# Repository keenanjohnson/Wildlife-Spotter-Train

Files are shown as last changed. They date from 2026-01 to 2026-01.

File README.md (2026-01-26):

# Wildlife Spotter Train



Explore the wilderness via Train! BLE-controlled LEGO City train using an ESP32-S3 microcontroller. Features real-time video streaming and playful interaction design. Currently in active development.

https://github.com/user-attachments/assets/2e25facd-4201-4223-821a-3176ae2201d8

This project is a Work in Progress but features:

- A small camera module attached to an ESP32-S3 microcontroller
- A 3D printed enclosure with integrated stand and antenna placement as well as LEGO compatible mounts
- Pybricks firmware running on the train to receive drive commands via Bluetooth
- ESP-IDF firmware on the camera module to stream video over UDP and send commands to the train via Bluetooth
- Fun

<p float="left">
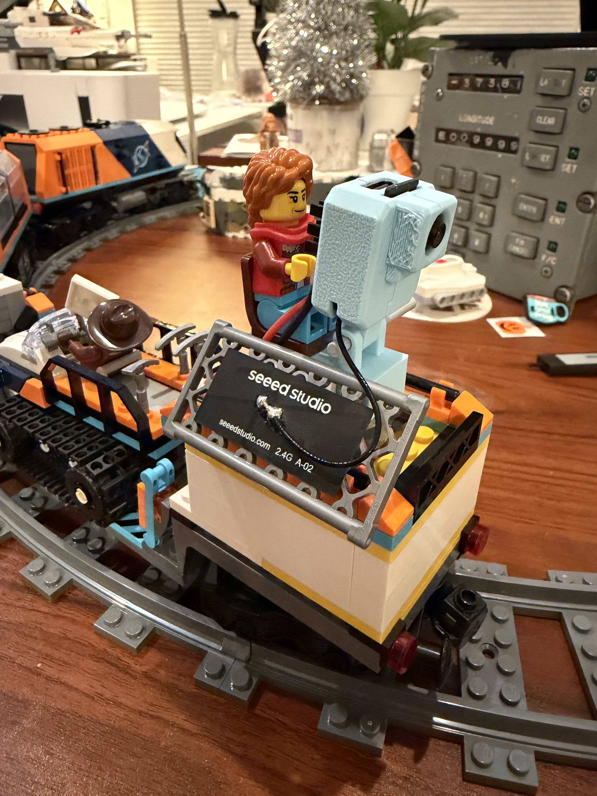
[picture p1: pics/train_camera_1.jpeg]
  
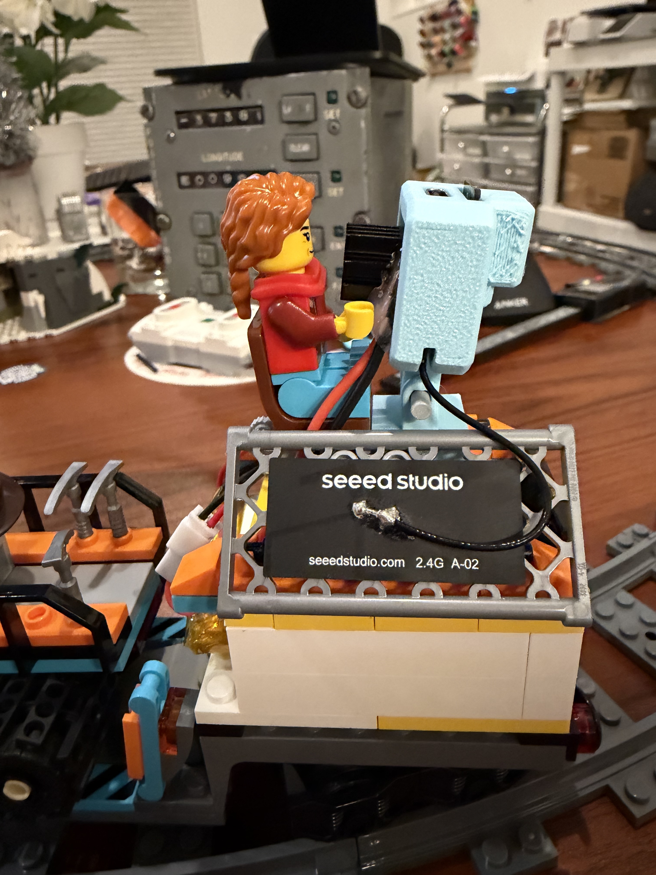
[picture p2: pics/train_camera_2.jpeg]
  
</p>

https://github.com/user-attachments/assets/5a5532dc-e645-4069-b709-44a688e2fda8

## The story

I recently found myself in possesion of one of the Lego artic train sets, which is among one of the most fun recent kits. [kit link #60470](https://www.lego.com/en-us/product/explorers-arctic-polar-express-train-60470). On the back of the artic train is a camera tripod for spotting wildlife, specifically the artic foxes that are included in the kit.



I have recently been doing much ecology and as an embedded systems engineer, I thought it would be fun to improve the set by adding a real camera to the kit.

Additionally, I had seen the excellent [Pybricks](https://pybricks.com/) project and realized that I could also make a device via Bluetooth control and software GUI that would not only stream video but also control the driving of the train.

## System Architecture

```
                                    ┌─────────────────────┐
                                    │      Browser        │
                                    │    train.local      │
                                    └──────────┬──────────┘
                                               │ WiFi (HTTP)
                                               │ - Web UI
                                               │ - MJPEG stream
                                               │ - Train controls
                                               ▼
┌─────────────────────┐  BLE GATT  ┌─────────────────────┐
│   LEGO City Hub     │◄───────────│      ESP32-S3       │
│    (Pybricks)       │   stdin    │   Camera Module     │
│                     │  commands  │                     │
│  - Motor control    │            │  - OV2640 camera    │
│  - LED feedback     │            │  - WiFi AP/STA      │
│  - main.py program  │            │  - NimBLE central   │
└─────────────────────┘            └─────────────────────┘
```

The ESP32-S3 serves as the central hub:
- **WiFi**: Hosts a web interface for video streaming and train controls
- **BLE**: Connects to the LEGO hub as a GATT client to send motor commands
- **Camera**: Captures JPEG frames and streams via MJPEG over HTTP

## Project Structure

| Directory | Description |
|---|---|
| [camera/src/](camera/src/) | ESP-IDF firmware for the ESP32-S3 camera module. Streams video and controls train via BLE. |
| [camera/cad/](camera/cad/) | 3D printable enclosure designs for the camera module. |
| [train/](train/) | Pybricks Python code that runs on the LEGO City hub to receive BLE commands. |
| [desktop/](desktop/) | Python test application for receiving and displaying UDP video frames. |

## Building

### Camera Firmware (ESP-IDF)

The camera firmware requires [ESP-IDF v5.5.2](https://docs.espressif.com/projects/esp-idf/en/v5.5.2/esp32s3/get-started/index.html). See [camera/src/README.md](camera/src/README.md) for detailed build and flash instructions.

```bash
cd camera/src
source ~/.espressif/v5.5.2/esp-idf/export.sh
idf.py set-target esp32s3
idf.py menuconfig  # Configure WiFi credentials
idf.py build
idf.py -p /dev/cu.usbmodem* flash monitor
```

### Train Controller (Pybricks)

The train runs [Pybricks firmware](https://pybricks.com/). See [train/README.md](train/README.md) for setup.

```bash
pip install pybricksdev
pybricksdev run ble my_program.py
```

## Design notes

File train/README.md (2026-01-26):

# Train Controller (Pybricks)

The code that runs via Pybricks firmware on the LEGO City Hub inside the train. The ESP32-S3 camera module connects to the hub via BLE and sends motor commands.

## Architecture

```
┌─────────────────┐     BLE GATT      ┌─────────────────┐
│   ESP32-S3      │ ──────────────────│  LEGO City Hub  │
│   (Camera)      │   stdin commands  │   (Pybricks)    │
│                 │                   │                 │
│  NimBLE Central │                   │  main.py        │
└─────────────────┘                   └─────────────────┘
```

## Programs

| File | Description |
|---|---|
| `main.py` | Production program - receives BLE stdin commands (F/B/S) and controls motor |
| `motor_test.py` | Standalone test - cycles motor forward/stop/backward without BLE |
| `check_ble.py` | Diagnostic - prints available Pybricks modules |

## Setup

```bash
# Create virtual environment (optional)
python -m venv env
source env/bin/activate

# Install pybricksdev
pip install pybricksdev

# Run program on hub (program stays installed after Ctrl+C)
pybricksdev run ble main.py
```

## Command Protocol

The ESP32 sends single-character commands via BLE stdin:

| Command | Action | Hub LED |
|---|---|---|
| `F` | Forward (30% power) | Green |
| `B` | Backward (30% power) | Blue |
| `S` | Stop | Yellow |

The program responds via stdout (visible in ESP32 logs):

| Response | Meaning |
|---|---|
| `RDY` | Program ready, accepting commands |
| `FWD` | Forward command acknowledged |
| `BWD` | Backward command acknowledged |
| `STP` | Stop command acknowledged |

## Pybricks BLE Protocol

This section documents the Pybricks BLE protocol for connecting external devices (like ESP32) to a Pybricks hub.

### Service and Characteristic UUIDs

```
Pybricks Service:        c5f50001-8280-46da-89f4-6d8051e4aeef
Pybricks Characteristic: c5f50002-8280-46da-89f4-6d8051e4aeef
```

### Command Codes (Write to Characteristic)

| Code | Name | Description |
|---|---|---|
| `0x00` | STOP_USER_PROGRAM | Stop the running program |
| `0x01` | START_USER_PROGRAM | Start the installed user program |
| `0x02` | START_REPL | Start interactive REPL |
| `0x03` | WRITE_USER_PROGRAM_META | Write program metadata |
| `0x04` | WRITE_USER_RAM | Upload program binary |
| `0x05` | REBOOT_TO_UPDATE_MODE | Enter firmware update mode (purple LED) |
| `0x06` | WRITE_STDIN | Write data to program's stdin |
| `0x07` | WRITE_APP_DATA | Write to app data buffer (v1.4.0+) |

**IMPORTANT**: Command `0x05` triggers firmware update mode, NOT stdin! Use `0x06` for stdin.

### Event Codes (Notifications from Characteristic)

| Code | Name | Description |
|---|---|---|
| `0x00` | STATUS_REPORT | Hub status flags (sent every ~500ms) |
| `0x01` | STDOUT | Data from program's print() statements |

### Status Report Flags (Event 0x00, Byte 1)

| Bit | Meaning |
|-----|---|
| 0x01 | Battery low |
| 0x02 | User program running |
| 0x40 | High current warning |

### Writing to stdin

To send data to a running program's stdin:

```
[0x06][data bytes...]
```

Example: Send "F" command
```
[0x06][0x46]  // 0x46 = ASCII 'F'
```

### Reading stdin in Pybricks

Use `stdin.buffer.read()` for raw bytes from BLE (not `stdin.read()`):

```python
from usys import stdin
from uselect import poll

keyboard = poll()
keyboard.register(stdin)

while True:
    if keyboard.poll(0):
        byte = stdin.buffer.read(1)  # Raw bytes from BLE
        if byte:
            cmd = chr(byte[0]).upper()
            # Process command...
```

**Key insight**: BLE stdin data arrives as raw bytes, so `stdin.buffer.read(1)` is required instead of `stdin.read(1)`.

## References

- [Pybricks BLE Profile](https://github.com/pybricks/technical-info/blob/master/pybricks-ble-profile.md)
- [Pybricks Hub-to-Device Communication](https://pybricks.com/projects/tutorials/wireless/hub-to-device/pc-communication/)
- [Brickrail BLE Implementation](https://github.com/Novakasa/brickrail/tree/master/ble-server)

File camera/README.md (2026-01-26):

# Camera Module

The camera module captures video from the train and streams it wirelessly to a desktop receiver. It uses a XIAO ESP32-S3 Sense board with an OV2640 camera sensor, housed in a custom 3D-printed enclosure.

## Features

- HD 1280x720 JPEG video streaming
- UDP-based transmission with chunked frames for reliability
- WiFi station mode with auto-reconnect
- Adaptive frame rate (33-1000ms based on conditions)

## Subfolders

- **[cad/](cad/)** - 3D-printable enclosure design (Onshape source + STL files)
- **[src/](src/)** - ESP-IDF C firmware for the ESP32-S3

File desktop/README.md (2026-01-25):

A basic test application to test receiving the UDP frames from the camera module.

## Install and Run

```
python -m venv env
source env/bin/activate
```

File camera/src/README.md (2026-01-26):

# ESP32-S3 Camera Firmware

MJPEG streaming server and BLE train controller for the Wildlife Spotter Train camera module.

## Architecture

```
┌─────────────────────────────────────────────────────────────────┐
│                         ESP32-S3 (Dual Core)                    │
│                                                                 │
│  ┌─────────────────────────────┐  ┌───────────────────────────┐ │
│  │          CORE 0             │  │          CORE 1           │ │
│  │                             │  │                           │ │
│  │  ┌───────────────────────┐  │  │  ┌─────────────────────┐  │ │
│  │  │   API Server (:80)    │  │  │  │ Stream Server (:81) │  │ │
│  │  │   - Web UI (/)        │  │  │  │ - MJPEG stream      │  │ │
│  │  │   - Capture (/capture)│  │  │  │ - Continuous loop   │  │ │
│  │  │   - Status (/status)  │  │  │  │                     │  │ │
│  │  │   - Train (/train)    │  │  │  └──────────┬──────────┘  │ │
│  │  └───────────────────────┘  │  │             │             │ │
│  │                             │  │             │             │ │
│  │  ┌───────────────────────┐  │  │  ┌──────────▼──────────┐  │ │
│  │  │   WiFi + NimBLE       │  │  │  │   Camera Driver     │  │ │
│  │  └───────────────────────┘  │  │  │   (JPEG capture)    │  │ │
│  │             │               │  │  └─────────────────────┘  │ │
│  └─────────────┼───────────────┘  └───────────────────────────┘ │
│                │                                                │
└────────────────┼────────────────────────────────────────────────┘
                 │ BLE                          │ WiFi
                 ▼                              ▼
       ┌─────────────────┐            ┌─────────────────┐
       │  LEGO City Hub  │            │     Browser     │
       │   (Pybricks)    │            │    (Web UI)     │
       └─────────────────┘            └─────────────────┘
```

### Dual-Core Design

The ESP32-S3 has two Xtensa LX7 cores. We split the workload to prevent the MJPEG streaming loop from blocking API requests:

| Core | Responsibility | Why |
|---|---|-----|
| **Core 0** | API server, WiFi, system tasks | Responsive to user interactions |
| **Core 1** | MJPEG streaming server | Continuous frame capture/send loop |

The MJPEG handler runs an infinite loop sending frames. Without core separation, this would block the single-threaded HTTP server from accepting new connections on other endpoints.

## mDNS / Bonjour

The camera advertises itself via mDNS, so you can access it without knowing the IP address:

| URL | Description |
|-----|---|
| `http://train.local/` | Web UI |
| `http://train.local/capture` | Single snapshot |
| `http://train.local/status` | Camera status JSON |
| `http://train.local:81/stream` | MJPEG stream |

mDNS works on macOS and Linux out of the box. On Windows, install [Bonjour Print Services](https://support.apple.com/kb/DL999).

## HTTP Endpoints

The firmware runs two HTTP servers to prevent the streaming handler from blocking other requests:

| Endpoint | Port | Description |
|---|---|---|
| `/` | 80 | Web UI with embedded video player and train controls |
| `/capture` | 80 | Single JPEG snapshot |
| `/status` | 80 | JSON camera status and settings |
| `/train` | 80 | Train control API (see below) |
| `/stream` | 81 | MJPEG video stream |
| `/` | 81 | MJPEG video stream (alias) |

### Train Control API

Control the LEGO train via the `/train` endpoint:

```bash
# Move forward
curl "http://train.local/train?action=forward"

# Move backward
curl "http://train.local/train?action=backward"

# Stop
curl "http://train.local/train?action=stop"

# Check status
curl "http://train.local/train?action=status"
```

Response format:
```json
{"status": "ok", "action": "forward", "train_state": "ready"}
```

### Example Usage

```bash
# View web UI (using mDNS hostname)
open http://train.local/

# Or using IP address directly
open http://192.168.1.6/

# Capture single frame
curl http://train.local/capture -o snapshot.jpg

# Get camera status
curl http://train.local/status

# Direct stream access
open http://train.local:81/stream
```

## Source Files

| File | Description |
|---|---|
| `main/main.c` | Entry point, initialization sequence |
| `main/camera.h` | OV3660 sensor configuration, pin mappings |
| `main/wifi_sta.h` | WiFi station mode, auto-reconnect logic |
| `main/mdns_service.h` | mDNS/Bonjour hostname advertisement |
| `main/http_server.h` | Dual HTTP servers, MJPEG streaming, REST endpoints |
| `main/web_ui.h` | Embedded HTML/CSS/JS web interface |
| `main/train_ble.h` | NimBLE GATT client for Pybricks hub communication |

## Camera Configuration

- **Sensor**: OV3660 (auto-detected, also supports OV2640)
- **Resolution**: HD 1280x720
- **Format**: JPEG (hardware encoding)
- **Quality**: 12/63 (lower = better quality)
- **Frame buffers**: 2 (continuous capture mode)
- **Frame buffer location**: PSRAM

## Build & Flash

### Prerequisites

```bash
# Source ESP-IDF environment
source ~/.espressif/v5.5.2/esp-idf/export.sh

# Set target (first time only)
idf.py set-target esp32s3
```

### WiFi Configuration

Before building, configure your WiFi credentials:

```bash
idf.py menuconfig
```

Navigate to **WiFi Configuration** and set your SSID and password. These settings are stored in `sdkconfig` which is gitignored.

### Build

```bash
idf.py build
```

### Flash & Monitor

```bash
idf.py -p /dev/cu.usbmodem* flash monitor
```

Press `Ctrl+]` to exit monitor.

## Performance

Typical performance on local WiFi:

| Metric | Value |
|---|---|
| Frame rate | 10-15 fps |
| Frame size | ~25 KB |
| Latency | 50-100 ms |
| Free heap | ~8 MB |

## Pin Configuration

```
OV3660 Camera Module:
  XCLK  = GPIO 10
  SIOD  = GPIO 40 (I2C SDA)
  SIOC  = GPIO 39 (I2C SCL)
  D7-D0 = GPIO 48,11,12,14,16,18,17,15
  VSYNC = GPIO 38
  HREF  = GPIO 47
  PCLK  = GPIO 13
  LED   = GPIO 21
```

## BLE Train Control

The ESP32-S3 acts as a BLE Central (GATT client) to control the LEGO City Hub running Pybricks firmware. WiFi and BLE run concurrently using the ESP32's coexistence feature.

### How It Works

1. **Scan**: ESP32 scans for devices advertising the Pybricks Service UUID
2. **Connect**: Connects to the hub and discovers the Pybricks characteristic
3. **Subscribe**: Enables notifications to receive stdout from the hub
4. **Start Program**: Sends command `0x01` to start the pre-installed user program
5. **Wait for Ready**: Waits for the program to print "RDY" via stdout
6. **Send Commands**: Writes stdin commands (`0x06` + data) to control the motor

### Configuration (sdkconfig.defaults)

```ini
# Bluetooth / NimBLE
CONFIG_BT_ENABLED=y
CONFIG_BT_NIMBLE_ENABLED=y
CONFIG_BT_NIMBLE_ROLE_CENTRAL=y
CONFIG_BT_NIMBLE_ATT_PREFERRED_MTU=158

# WiFi/BLE Coexistence
CONFIG_ESP_COEX_SW_COEXIST_ENABLE=y
CONFIG_ESP_COEX_POWER_MANAGEMENT=y
```

### Connection States

| State | Description |
|---|---|
| `disconnected` | Not connected, will scan |
| `scanning` | Scanning for Pybricks hub |
| `connecting` | Found hub, connecting |
| `discovering` | Connected, discovering services |
| `initializing` | Starting user program |
| `ready` | Program running, accepting commands |

### Prerequisites

Before the ESP32 can control the train:

1. Flash Pybricks firmware to the LEGO City Hub
2. Install the train program: `pybricksdev run ble train/main.py`
3. The program stays installed after Ctrl+C

See [train/README.md](../../../train/README.md) for the Pybricks BLE protocol details.

## Credits

The initial ESP-IDF structure was heavily inspired by: https://github.com/wrsturgeon/esp32s3-video-stream

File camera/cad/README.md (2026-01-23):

This is the mechanical design and 3D printing files for the camera enclosure.

The source files are made in onshape and can be found here: https://cad.onshape.com/documents/eec496f84c3496d012ae1f5b/w/9621dc89637b804ab2f42b21/e/75a9e618d3a58e29e14f7084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

## Current Progress

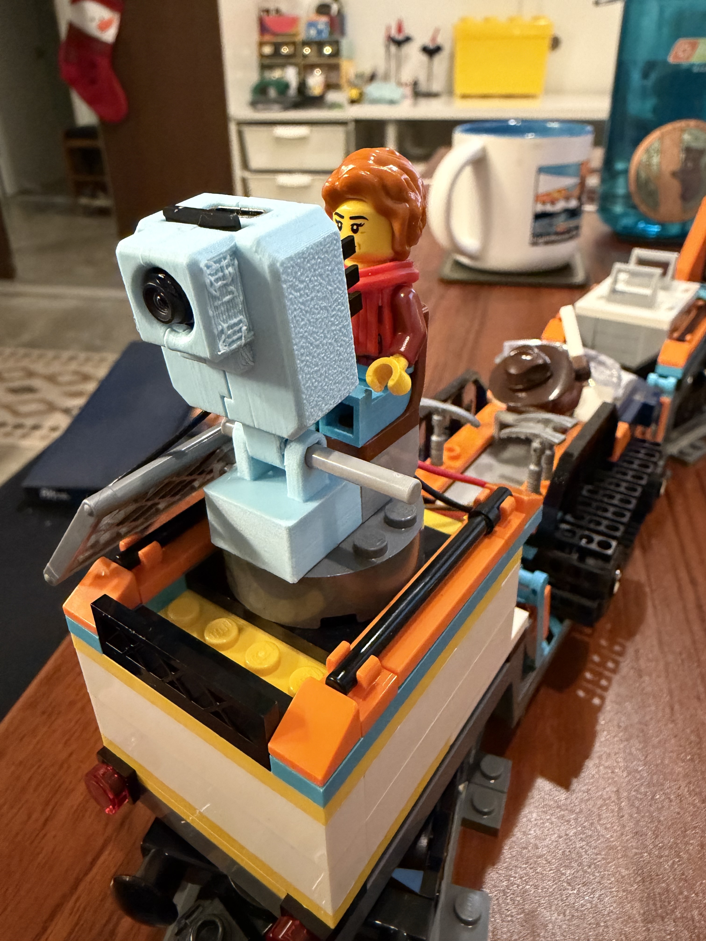
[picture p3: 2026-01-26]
pics/train_camera_3.jpeg

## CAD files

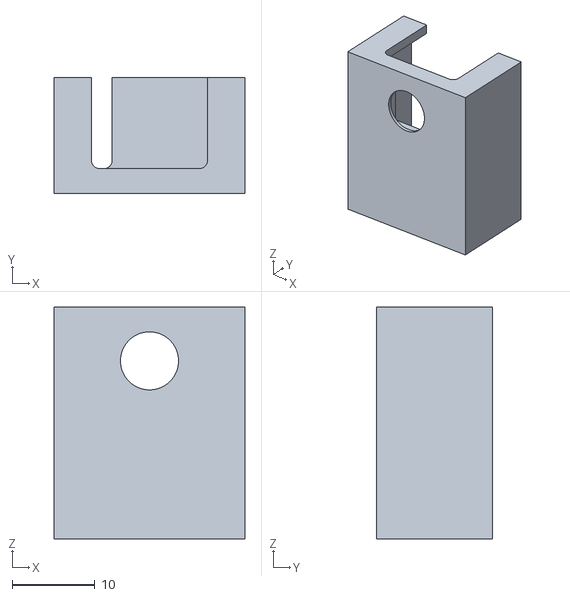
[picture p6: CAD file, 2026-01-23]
camera/cad/xiao-case - xiao-case.stl
23.0 x 14.0 x 28.0

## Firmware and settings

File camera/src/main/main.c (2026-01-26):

#include <esp_log.h>
#include <esp_system.h>
#include <string.h>
#include <stdio.h>

#include <freertos/FreeRTOS.h>
#include <freertos/task.h>

// support IDF 5.x
#ifndef portTICK_RATE_MS
#define portTICK_RATE_MS portTICK_PERIOD_MS
#endif

#include <esp_camera.h>
#include <esp_timer.h>
#include <esp_wifi.h>
#include <esp_netif.h>
#include <esp_event.h>
#include <esp_http_server.h>

#include "camera.h"
#include "wifi_sta.h"
#include "mdns_service.h"
#include "web_ui.h"
#include "train_ble.h"
#include "http_server.h"

static char const *const TAG = "CAMERA-MAIN";

void app_main(void) {
    // Early debug output
    printf("\n\n=== APP_MAIN STARTED ===\n");
    fflush(stdout);
    vTaskDelay(pdMS_TO_TICKS(100));

    ESP_LOGI(TAG, "Wildlife Spotter Train - MJPEG Streaming Server");
    ESP_LOGI(TAG, "Free heap at start: %lu bytes", (unsigned long)esp_get_free_heap_size());

    // Initialize WiFi station:
    ESP_LOGI(TAG, "Initializing WiFi...");
    wifi_init_sta();
    ESP_LOGI(TAG, "WiFi init complete. Free heap: %lu bytes", (unsigned long)esp_get_free_heap_size());

    // Wait for WiFi to connect before starting BLE (coexistence requires WiFi up first)
    ESP_LOGI(TAG, "Waiting for WiFi connection...");
    if (wifi_wait_connected(15000)) {
        ESP_LOGI(TAG, "WiFi connected successfully!");
    } else {
        ESP_LOGW(TAG, "WiFi connection timeout, continuing anyway...");
    }

    // Small delay to let WiFi stabilize before starting BLE
    vTaskDelay(pdMS_TO_TICKS(500));

    // Initialize BLE for train control
    ESP_LOGI(TAG, "Initializing train BLE...");
    train_ble_init();
    ESP_LOGI(TAG, "Train BLE init complete. Free heap: %lu bytes", (unsigned long)esp_get_free_heap_size());

    // Start mDNS service (allows access via wildlife-train.local)
    ESP_LOGI(TAG, "Starting mDNS service...");
    start_mdns_service();

    // Initialize camera:
    ESP_LOGI(TAG, "Initializing camera...");
    init_camera();
    ESP_LOGI(TAG, "Camera init complete. Free heap: %lu bytes", (unsigned long)esp_get_free_heap_size());

    // Start HTTP server with MJPEG streaming:
    ESP_LOGI(TAG, "Starting HTTP server...");
    start_http_server();
    ESP_LOGI(TAG, "HTTP server started. Free heap: %lu bytes", (unsigned long)esp_get_free_heap_size());

    ESP_LOGI(TAG, "System ready!");

    // Main loop - just keep the task alive and log memory stats periodically
    while (1) {
        vTaskDelay(pdMS_TO_TICKS(30000)); // Every 30 seconds

        ESP_LOGI(TAG, "Free heap: %lu bytes, min free: %lu bytes",
            (unsigned long)esp_get_free_heap_size(),
            (unsigned long)esp_get_minimum_free_heap_size());
    }
}

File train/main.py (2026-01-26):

# Train control via stdin commands (single character)
# Install this program to the hub, then ESP32 can connect via GATT

from pybricks.hubs import CityHub
from pybricks.parameters import Color, Port
from pybricks.tools import wait
from pybricks.pupdevices import DCMotor
from usys import stdin
from uselect import poll

# Initialize the hub and motor
hub = CityHub()
train_motor = DCMotor(Port.A)

# Set up stdin polling for non-blocking reads
keyboard = poll()
keyboard.register(stdin)

# Signal ready
hub.light.on(Color.GREEN)
print("RDY")

while True:
    # Check for incoming commands via stdin (from BLE GATT)
    # Use stdin.buffer.read() for raw bytes from BLE
    while keyboard.poll(0):
        byte = stdin.buffer.read(1)
        if byte:
            cmd = chr(byte[0]).upper()
            if cmd == "F":
                train_motor.dc(30)
                hub.light.on(Color.GREEN)
                print("FWD")
            elif cmd == "B":
                train_motor.dc(-30)
                hub.light.on(Color.BLUE)
                print("BWD")
            elif cmd == "S":
                train_motor.dc(0)
                hub.light.on(Color.YELLOW)
                print("STP")
            # Ignore other characters

    wait(50)

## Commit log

2026-01-23 Add xiao cad
2026-01-23 Initial case cad
    [xiao-case - xiao-case.stl]
2026-01-25 Camera: Switch from Micropython to ESP-IDF C Program (#1)
2026-01-26 Add basic camera readme
2026-01-26 Increase framerate (#3)
2026-01-26 Implements Train Control (#4)
    * Add train requirements
    * Add basic train control script
    * Enable bluetooth
    * Add first hack at BLE
    * esp bluetooth gatt works
    * update
    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
    [partitions.csv]
